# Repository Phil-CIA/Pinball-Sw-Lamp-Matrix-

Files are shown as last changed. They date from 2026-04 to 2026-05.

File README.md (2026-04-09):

# Pinball Switch + Lamp Matrix Board

8x4 lamp matrix driver and 8x4 switch matrix scanner board for a pinball machine.

## Architecture (current)
- **Lamp rows (8):** high-side smart switches (2× `VNQ7E100AJTR`, 4ch each)
- **Lamp columns (4):** low-side MOSFET sinks
- **Switch columns (4):** `LMV393` comparators (5V powered, OD outputs pulled up to 3.3V)
- **Output expansion:** 2× `74HC595` @ 3.3V for deterministic row/column bit patterns

## Repo layout
- `hardware/` – KiCad project files and production exports
- `firmware/` – PlatformIO / ESP-IDF bring-up firmware
- `docs/` – design notes, project status, review notes, and bring-up plans
- `BOM/` – key part numbers and alternates

## Project references
- `docs/PROJECT_STATUS.md` – current state, locked assumptions, and active priorities
- `docs/NEXT_ITERATION.md` – parking lot for ideas, risks, and restart notes
- `docs/SCHEMATIC_REVIEW.md` – design review and cleanup notes captured during the pre-order review
- `docs/BRINGUP_CHECKLIST.md` – first-board arrival, assembly, and power-up checklist
- `docs/PINMAP.md` – signal naming, connector grouping, and board-mating draft map
- `docs/PCB_REVIEW_CHECKLIST.md` – pre-order hardware checklist
- `docs/GITHUB_REPO_SETUP.md` – suggested GitHub repo metadata and settings
- `BOM/key_parts.md` – important component choices
- `CONTRIBUTING.md` – repo workflow and update expectations
- `SECURITY.md` – reporting guidance for risky or security-related issues
- `CHANGELOG.md` – notable repo changes over time

## Status
Rev 1 hardware was ordered on **2026-04-09**.

- **Hardware:** schematic, PCB snapshots, Gerbers, drill files, BOM, and production ZIP are checked in under `hardware/`
- **Order state:** PCB + stencil ordered, with parts ordered separately
- **Current phase:** wait for hardware and prepare bench bring-up
- **Firmware:** verified ESP32-C6 ESP-IDF bring-up scaffold is present under `firmware/`

## Next Steps
- keep the ordered Rev 1 package and notes as the reference point
- assemble and inspect the first boards when they arrive
- short-check `18V`, `5V`, and `3.3V` before full power-up
- validate ESP32, shift-register outputs, and switch-column reads on bench hardware
- run one-row / one-column lamp tests, then a full matrix scan
- capture any Rev 2 findings after first hardware validation

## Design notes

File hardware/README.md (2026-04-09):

# Hardware Notes

This folder contains the KiCad project files and production exports for the pinball switch + lamp matrix board.

## Current state
- `Pinball Matrix board Rev 1.kicad_sch` is the checked-in schematic source for Rev 1.
- `hardware/` also contains routed PCB snapshots, Gerbers, drill files, a BOM CSV, and the zipped production package used for ordering.
- Rev 1 PCB + stencil were ordered on `2026-04-09`; treat the ordered files as the frozen reference until hardware bring-up starts.

## Recommended use
1. Use `../docs/SCHEMATIC_REVIEW.md` for design review context and accepted tradeoffs.
2. Use `../docs/BRINGUP_CHECKLIST.md` when the first boards arrive.
3. Record any assembly or bench findings back into `../docs/NEXT_ITERATION.md` and `../docs/PROJECT_STATUS.md`.

## Caution
- More than one PCB snapshot exists in this folder (`pre route`, `routed`, `routed power`).
- If a post-order edit is made, clearly note whether it belongs to the frozen Rev 1 archive or to future Rev 2 work.

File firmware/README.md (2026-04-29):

# Firmware

Preferred workflow: **PlatformIO** using the verified **ESP-IDF** environment for ESP32-C6.

## Layout
- `src/` - production firmware entry point (PlatformIO default)
- `bringup/` - one-off test programs and notes

## Build (PlatformIO)
From `firmware/`:
- `python -m platformio run`
- `python -m platformio run -t upload --upload-port COM4`
- `python -m platformio device monitor --port COM4 --baud 115200`

If ESP-IDF tool version checks block a local bring-up build, run in the same shell session:
- PowerShell: `$env:IDF_MAINTAINER='1'`

## Notes
- Verified on 2026-04-06: `esp32-c6-devkitm-1` currently builds with `framework = espidf` in PlatformIO.
- If you later move to a board definition with Arduino support, an Arduino environment can be added back into `platformio.ini`.
- Update the `board = ...` value in `platformio.ini` if your exact ESP32-C6 dev kit differs.
- For this repository, build from the no-space path (`C:\cfhe\Pinball-Sw-Lamp-Matrix\firmware`) when possible. Path whitespace has caused intermittent ESP-IDF failures.

## Bring-up Runtime Modes (2026-04-29)
Current firmware provides fixed bring-up runtime behavior selected in `src/main.cpp` using `kRuntimeMode`.

Available modes:
- `RuntimeMode::LampAttract`
	- Low-duty attract chase for lamp mapping and brightness sanity
	- Timing controlled by `ATTRACT_SLOT_MS` and `ATTRACT_ON_MS`
- `RuntimeMode::SwitchScan`
	- Rows are scanned continuously with lamp columns held off
	- Switch-column reads are sampled per row and accumulated
	- Serial prints include:
		- `HB ...`
		- `SWITCH_SCAN row=... hits[rX]=...`
		- `SW_EDGE/s: ...`
		- `CTRL_I2C edges/s: ...`
- `RuntimeMode::I2cSlaveRegmap` (current default)
	- Matrix board exposes I2C slave register map at `0x24` on `GPIO2/GPIO3`
	- Registers and commands align to control-board contract (`0x00..0x07`, `0x40..0x43`, `0xF0..0xF3`, `0x20/0x80/0xE0`)
	- OLED remains active in this mode using software I2C on `GPIO7/GPIO6`
	- OLED view includes banner status, live 8x5 lamp grid, and link telemetry pane
	- Link state detection includes `WAIT`, `LIVE`, and `DEGRADED` (TX stall)

## Current validated pin map
- Shift register drive:
	- `S_Data = GPIO15`
	- `S_CLK = GPIO22`
	- `S_latch = GPIO23`
	- `SR_/OE = GPIO10` (driven low to enable outputs)
- Switch comparator outputs:
	- `SW_COL_0 = GPIO18`
	- `SW_COL_1 = GPIO19`
	- `SW_COL_2 = GPIO20`
	- `SW_COL_3 = GPIO21`
- OLED:
	- `SDA = GPIO7`
	- `SCL = GPIO6`

## Quick verify sequence
1. Build and upload from `C:\cfhe\Pinball-Sw-Lamp-Matrix\firmware`
2. Open serial monitor on COM4
3. Confirm startup shows `Runtime mode: I2C_SLAVE_REGMAP ...`
4. Confirm `ssd1306_sw_init(GPIO7/6 @0x3C) -> 0 (ESP_OK)`
5. Confirm per-second updates show `HB`, `I2C_SLAVE ...`, and `LINK state=...`

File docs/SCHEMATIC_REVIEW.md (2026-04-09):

# Schematic Review and Cleanup Notes

Review dates: **2026-04-06** and follow-up **2026-04-07**

This note captures the current schematic cleanup work that should be finished **before spending time routing the PCB**.

Scope reviewed:
- `hardware/Pinball Matrix board Rev 1.kicad_sch`
- repo documentation and footprint/library setup

> This is a schematic/design review note based on the checked-in KiCad source and repo contents. It should be used as the cleanup guide before layout work continues.

---

## Follow-up review status (2026-04-07)
- Fresh repo check showed `git status -sb` clean.
- The currently saved KiCad files in `hardware/` show `LastWriteTime` around **2026-04-06 7:28 AM**, so the repo copy available for review is **not within the last hour**.
- An updated netlist is **not required** for this text/design review, but a saved netlist/ERC export would help with deeper connectivity cross-checking later.
- Because no newer KiCad save was visible in the repo copy, the block-by-block notes below apply to the **current saved schematic version**.

---

## Current pre-order repo status (2026-04-09)
- Latest repo state includes **production-oriented outputs** under `hardware/`, including:
  - routed PCB snapshots
  - BOM CSV
  - gerbers / drill files
  - zipped production package
- Current source review shows several earlier concerns are now effectively addressed:
  - `U3` now uses a dedicated `ESP32-C6-DevKit-Amazon` footprint entry
  - test points are assigned to `KEYSTONE_5015`
  - output connectors use `.156" / 3.96 mm` KK-396 style footprints
  - power input plan uses JST XH connectors with shared `18V` and `GND` pins, and a separate lighter-current `5V` pair
  - planned routing approach uses `0.3 mm` minimum signal traces and `2.0–2.5 mm` row-current traces with VNQ thermal-pad stitching
- Based on the schematic/block review to date, **no show-stopper has been identified** for moving forward with Rev 1.
- Remaining caution items before ordering are mostly execution checks:
  - run KiCad ERC/DRC on the exact final file you intend to order
  - confirm the authoritative PCB/gerber set among the saved routed snapshots
  - sanity-check connector pin order and polarity one last time against the harness

## High-priority items before PCB routing

| Priority | Item | Review note / action |
|---|---|---|
| High | `JD1` connector mismatch | `JD1` uses a `Conn_01x24_MountingPin` symbol while the assigned footprint is `Connector_Molex:Molex_KK-396_5273-12A_1x12_P3.96mm_Vertical`. The symbol pin count and footprint pin count must be made consistent. |
| High | `U2` controller footprint mismatch | `U2` is labeled `ESP32-C6-DevKitM-Amazon`, but the assigned footprint is `RF_Module:ESP32-C3-DevKitM-1`. Confirm the actual controller board/module and correct the footprint now. |
| High | `U5` / `U6` comparator package choice | `LMV393` is present, but the final footprint/package choice still needs to be locked down and verified against the intended assembly plan. |
| High | Test-point footprints | `TP6`–`TP15` should be assigned the chosen small SMT test-point footprint (`Keystone 5015` was selected). |
| High | `F1` / `F2` polyfuse footprints | Polyfuse footprints still need to be replaced with a real KiCad footprint instead of placeholder-style text. |
| High | Ground strategy | `GND` and `GNDD` are both used in the schematic. Decide whether they remain split or are tied intentionally with a documented single-point/net-tie strategy. |

## Medium-priority cleanup items

- **Normalize signal naming** to match `docs/PINMAP.md`
  - `S_CLK` → `SR_SCLK`
  - `S_latch` → `SR_LATCH`
  - `S_Data` → `SR_DATA0`
  - `S_Data_1` → `SR_DATA1`
  - `Sw_Col_0...3` → `SW_COL_0...3`
- **Remove duplicated naming styles** such as:
  - `+3.3V` vs `+3V3`
  - `I2C SCL` vs `I²C SCL`
  - `Row 3` vs `Row_3`
- **Confirm connector family callouts**
  - some connector values use `B4B-XH-A` while footprints point to JST EH footprints; verify the actual intended family/pitch
- **Rename MOSFET references consistently**
  - devices using value `IRLR024` should use transistor-style references (`Qx`) instead of inductor-style references if they are MOSFETs
- **Review optional EMI tuning parts**
  - ferrites/snubber parts should be marked and documented as default-fit vs DNP for rev A
- **Re-check bulk capacitor assumptions**
  - verify voltage rating, technology, and effective capacitance on the 18V lamp rail

## Block-by-block design review

### 1) Power entry and protection
- Good signs: PTC fuses, TVS parts, and bulk/decoupling capacitors are present in the schematic.
- Follow-up review on 2026-04-08: moving to physically larger **per-rail TVS parts** is acceptable and can improve layout/rework, as long as the standoff/clamp ratings still match each rail.
- Before routing, confirm real footprints for `F1` / `F2`, verify the bulk-cap voltage margin on the lamp rail, and keep the TVS return path physically short and wide.
- Keep the fuse upstream of the TVS in the final PCB layout.

### 2) Lamp row driver block (`VNQ7E100AJTR`)
- The 8-row high-side architecture still fits the intended lamp-matrix design.
- Confirm EPAD grounding, strap-pin defaults, and any unused-channel handling before layout.
- Keep the row outputs and connector naming aligned with `docs/PINMAP.md`.

### 3) Lamp column sink block
- The low-side sink approach still looks appropriate for the matrix concept.
- Main cleanup item: confirm package/current capability and use consistent transistor-style references for MOSFET parts.
- Verify any gate resistors, pulldowns, and EMI/ringing mitigation parts you want stuffed by default.

### 4) Switch input comparator block (`LMV393` + clamps)
- The comparator-based switch readback approach is still reasonable for the design.
- Follow-up review on 2026-04-08 against the updated source confirms `LMV393` comparators with `BAT54C,215` clamp diodes and the expected `Ref_Comp1` / `Ref_Comp2` reference network.
- I do **not** see a stop-the-design issue here; the block concept looks fine for now.
- Keep the comparator outputs clearly referenced to the 3.3V logic side, and only add hysteresis later if bench testing shows chatter or noise around the threshold.
- No exposed-pad package is needed here; a standard SOIC-8 / TSSOP-8 style comparator package remains the practical choice.

### 5) Shift-register / logic-output block (`74HC595`)
- This block still matches the firmware bring-up concept.
- `/OE` and `/MR` should have explicit boot-safe defaults so the lamps do not glitch during startup.
- Normalize the control-net labels to `SR_SCLK`, `SR_LATCH`, `SR_DATA0`, and `SR_DATA1`.

### 6) Controller / dev-board block (`U2`)
- This remains a top cleanup item because the symbol name and assigned footprint do not yet agree.
- Confirm whether the design is targeting a temporary dev board, a module footprint, or a board-to-board control header.
- If GPIO assignments change, keep `docs/PINMAP.md` and firmware notes synchronized.

### 7) Connectors, test points, and board mating
- Connector families and exact pin counts still need to be frozen before routing.
- `JD1` must be corrected before layout because the symbol and footprint currently disagree.
- Assign the chosen `Keystone 5015` footprint to the debug test points and keep the board-mating notes in `docs/PINMAP.md` up to date.

## Repo / footprint-library cleanup

The schematic currently references external or non-portable footprint/library names such as:
- `PCM_JLCPCB:*`
- `Captain fantastic footprints:*`
- `POWERSSO-16_STM`

### Repo risk
At review time, the repo does **not** contain tracked KiCad footprint libraries (`*.kicad_mod`) or symbol libraries (`*.kicad_sym`). That means footprint resolution depends on the local KiCad environment.

### Recommended fix
Choose one of these approaches before layout gets deeper:
1. **Commit required custom footprints/libraries into the repo** under a dedicated hardware library folder, or
2. **Document the required external libraries clearly** in `hardware/README.md` so the project opens predictably on another machine.

## Suggested cleanup order
1. Lock the exact controller/dev-board footprint for `U2`
2. Fix `JD1` symbol-to-footprint pin-count mismatch
3. Assign/confirm comparator, fuse, and test-point footprints
4. Normalize signal names to match `docs/PINMAP.md`
5. Decide and document `GND` vs `GNDD`
6. Re-run a formal KiCad ERC/footprint check in KiCad before routing continues

## Notes to carry into PCB layout
- Keep the logic/debug connector and lamp-power connector concerns clearly separated
- Keep test points on logic/control nets easy to probe
- Do not assume all custom footprints will resolve on a fresh machine unless the repo includes them or the setup is documented

## Pre-routing go / no-go checklist

Before committing to the heavy PCB routing, confirm these items:

- [ ] **Row current estimate is written down**
  - worst-case active row current for the `555` lamp matrix is understood and accepted
- [ ] **Connector current handling is acceptable**
  - input and output connectors are confirmed for real machine wiring/current pulses
- [ ] **Trace widths are chosen in mm**
  - lamp supply and high-current row/column paths are planned around the agreed wider copper approach
- [ ] **VNQ thermal plan is intentional**
  - copper area, pad treatment, and short current paths are accounted for
- [ ] **Power-entry return paths are short and wide**
  - fuse, TVS, bulk caps, and ground return placement are kept tight
- [ ] **Comparator reference area is kept quiet**
  - threshold/reference nodes are not sharing thin noisy returns with lamp current
- [ ] **Connector pin order is frozen before routing**
  - avoid rework after the large current paths are already placed
- [ ] **Any DNP/tuning parts are clearly marked**
  - especially EMI/filtering options on lamp outputs

If these are mostly true, the board is in a reasonable state to continue routing.

## Review log
- 2026-04-06: initial schematic cleanup review captured in repo documentation.
- 2026-04-07: follow-up review confirmed the repo copy had no newly saved KiCad files and added a block-by-block design review section.
- 2026-04-08: pulled the latest remote KiCad updates; confirmed the switch-input comparator block and larger rail-TVS direction are conceptually acceptable.

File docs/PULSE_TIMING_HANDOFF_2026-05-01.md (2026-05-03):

# Pulse Timing Handoff - 2026-05-01

Status: Local implementation drafted on this workstation, not yet built or bench-validated.
Scope: Matrix shift-register timing, lamp-first row sequencing, and follow-on switch sampling placement.

## Why this handoff exists
The important point from today's review is that determinism has to come from the shift-register write itself.
The time-critical primitive should do only this:

1. Take the current row/column image.
2. Apply the intended row/column value.
3. Clock and latch the frame.

No scan logic, no conditional behavior, and no readback work should live inside that primitive.
That keeps row-to-row edge placement repeatable and makes the logic analyzer captures interpretable.

## Current status on this workstation
Primary source file: firmware/src/main.cpp

Local edits have already been made in that file to move the non-attract scan path to an explicit scheduler with microsecond deadlines.
The scheduler now uses these phases:

1. Blank
2. Drive
3. Settle
4. Sample
5. Hold

The current local implementation also separates row and column SR writes instead of relying on one combined row transition.

Important limitation: this workstation shell does not have ESP-IDF initialized, so the change has not been built here. `idf.py` was not available on `PATH`, and editor diagnostics only reported missing ESP-IDF include paths.

## Lamp-first design decision
The same base SR routine applies to both lamp drive and switch scanning, but the next bench target should be lamp timing first.
Reason: if row and column transitions are electrically clean for lamps, the same scheduler structure gives a stable foundation for switch sampling afterward.

The intended per-row write order is:

1. Blank write: all rows off, all columns off.
2. Row-on write: target row active, columns still off.
3. Column-on write: same row active, desired columns driven.
4. Settle delay: allow external hardware to reach a stable state.
5. Sample point: used for switches later, at a fixed delay from the final latch.
6. Columns-off write: same row still selected, columns forced off.
7. Dead-time: short off interval to cover driver/storage/RC recovery.
8. Row-off write: force row inactive before the next row begins.

This ordering avoids both of the bad overlap cases:

- new row with old columns
- old row with new columns

## Timing model to bench-tune
Current local constants in firmware/src/main.cpp:

- `SWITCH_SCAN_ROW_MS = 5`
- `ROW_BLANK_US = 100`
- `ROW_SETTLE_US = 100`
- `ROW_OFF_DEADTIME_US = 50`

These are starting values only. The MCU is not the limiting factor; the external devices are. Budget must cover:

- shift-register propagation and latch behavior
- row-driver turn-on and turn-off timing
- column-line RC settling
- any analog or GPIO recovery before a sample is trusted

## What was changed locally
In firmware/src/main.cpp, the local uncommitted edit does the following:

1. Adds a dedicated `RowPhase` enum and `RowScheduler` state.
2. Adds `sr_write_image(rowByte, colByte)` so the SR write path stays simple and constant-time.
3. Replaces the old coarse row-step logic with explicit microsecond phase deadlines.
4. Splits non-attract row service into separate writes for row-only and row-plus-columns.
5. Moves switch sampling to the fixed post-settle sample phase.
6. Adds heartbeat visibility for scheduler phase and overrun count.

This is the right direction, but it still needs a real build and bench capture before commit.

## Outstanding files to carry and commit
As of this handoff, the matrix repo has these outstanding modified files:

- `firmware/src/main.cpp`
- `docs/PULSE_TIMING_HANDOFF_2026-05-01.md`

Control-board repo on this workstation showed no outstanding changes.

## Required validation on the other workstation
Use an ESP-IDF-enabled shell on the other workstation.

1. Pull the latest matrix repo state from the remote.
2. Bring over or reapply the local edits if they are not yet committed.
3. Run `idf.py build` in the firmware directory.
4. Capture LA traces on at least: row output, SR latch, SR clock, and one column input.
5. Confirm this sequence electrically:
   - blank frame
   - row-on / columns-off frame
   - row-on / columns-on frame
   - settle interval
   - sample instant
   - columns-off frame
   - row-off frame
6. Tune `ROW_BLANK_US`, `ROW_SETTLE_US`, and `ROW_OFF_DEADTIME_US` until overlap is gone and timing is repeatable.

## Commit target after validation
If the build passes and the waveform looks correct, commit the two modified matrix files above as the timing-stabilization checkpoint.

Suggested commit scope:

- deterministic SR scheduler and explicit row/column timing sequence
- updated handoff notes with lamp-first validation plan

## Non-goals for this pass
Do not widen this pass into gameplay or control integration yet.
Still out of scope until the lamp timing is proven:

- control-board solenoid coupling
- scoring behavior
- audio parity work
- broader protocol feature work beyond what is needed to exercise lamp timing

## Immediate next action on the other workstation
Open an ESP-IDF shell, build the matrix firmware, bench the lamp waveform first, then commit the outstanding matrix files once the timing constants are validated.

Last updated: 2026-05-03
Owner for next step: bench firmware dev workstation

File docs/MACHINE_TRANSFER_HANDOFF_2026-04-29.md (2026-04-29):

# Machine Transfer Handoff - 2026-04-29

## Snapshot
- Repo: `Pinball-Sw-Lamp-Matrix`
- Branch: `main` (local working tree has uncommitted housekeeping updates)
- Active firmware mode: `RuntimeMode::I2cSlaveRegmap` in `firmware/src/main.cpp`
- Control-link role: matrix board as I2C slave at `0x24` on `GPIO2/GPIO3`
- OLED role: active in slave mode using software I2C on `GPIO7/GPIO6`

## What Was Completed Today
1. Implemented and stabilized matrix I2C slave register map flow.
2. Added diagnostics and cleaned telemetry counters (`badWrites` vs `ignoredWrites`).
3. Re-enabled OLED output while slave mode is active using software I2C.
4. Added OLED display contract v1:
   - top banner status elements
   - 8x5 matrix grid from lamp row buffer
   - right telemetry pane (sweep / trace)
   - link states (`WAIT`, `LIVE`, `DEGRADED`) with TX-stall detection
5. Housekeeping updates made in:
   - `firmware/src/main.cpp`
   - `firmware/README.md`
   - `CHANGELOG.md`

## Current Constraints
- BAT54 switch-path hardware update is pending (user has BAT54S incoming).
- Switch validation is intentionally deferred until BAT54S replacement is complete.
- PlatformIO build still reports flash warning:
  - expected 4MB, detected 2MB
  - currently non-blocking for bring-up workflow

## Verified Runtime Evidence
- Build succeeds from no-space path: `C:\cfhe\Pinball-Sw-Lamp-Matrix\firmware`
- Upload succeeds on COM4.
- Boot log confirms:
  - `Runtime mode: I2C_SLAVE_REGMAP addr=0x24 SDA=GPIO2 SCL=GPIO3`
  - `ssd1306_sw_init(GPIO7/6 @0x3C) -> 0 (ESP_OK)`
- Link telemetry shows active `rx/tx` progression and link state output.

## Next Mainline Steps
1. Keep default mode in `I2cSlaveRegmap` until switch hardware is updated.
2. After BAT54S install:
   - validate physical switch closures against registers `0x40..0x43`
   - confirm no false edges/noise
3. Run control-link acceptance checks:
   - stable `LIVE` state
   - no sustained `DEGRADED`
   - lamp row writes reflected correctly in grid/buffer

## Resume Commands
From PowerShell:

```powershell
Set-Location C:\cfhe\Pinball-Sw-Lamp-Matrix\firmware
C:\Users\user\.platformio\penv\Scripts\platformio.exe run
C:\Users\user\.platformio\penv\Scripts\platformio.exe run --target upload
C:\Users\user\.platformio\penv\Scripts\platformio.exe device monitor --port COM4 --baud 115200
```

## Git Checklist Before Push
If you want to capture this checkpoint as a commit:

```powershell
Set-Location C:\cfhe\Pinball-Sw-Lamp-Matrix
git status --short
git add firmware/src/main.cpp firmware/README.md CHANGELOG.md docs/MACHINE_TRANSFER_HANDOFF_2026-04-29.md
git commit -m "Matrix slave+OLED integration: display v1, link states, and housekeeping"
git push
```

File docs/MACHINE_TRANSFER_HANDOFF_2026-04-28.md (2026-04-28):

# Machine Transfer Handoff (2026-04-28)

Purpose: resume matrix-board bring-up tomorrow from another machine, then continue execution here with minimal context loss.

## Repo and Branch
- Repo: `Phil-CIA/Pinball-Sw-Lamp-Matrix-`
- Branch: `main`
- Working tree status at handoff creation: clean

## Last Pushed Commits (newest first)
- `0d4cc17` Ignore local bring-up capture logs
- `850f767` Checkpoint: Rev1 hardware edits and firmware platform config
- `8a48dfa` Add switch-scan bring-up mode and update checkpoint docs

## Current Firmware State (Matrix Repo)
- File: `firmware/src/main.cpp`
- Runtime mode selector exists:
  - `RuntimeMode::LampAttract`
  - `RuntimeMode::SwitchScan`
- Current default is:
  - `kRuntimeMode = RuntimeMode::SwitchScan`
- Validated pins:
  - Shift register: `DATA=GPIO15`, `CLK=GPIO22`, `LATCH=GPIO23`, `OE_N=GPIO10`
  - Switch columns: `SW_COL_0..3 = GPIO18..GPIO21`
  - OLED: `SDA=GPIO7`, `SCL=GPIO6`
  - Control-link monitor: `SDA=GPIO2`, `SCL=GPIO3`

## Bench Findings So Far
- Lamp hardware path now mostly functional after correcting swapped gate resistor placements on 3 of 4 lamp columns.
- Brightness concern addressed in firmware by low-duty attract pulse timing.
- Switch validation mode implemented and running with telemetry:
  - `HB ...`
  - `SWITCH_SCAN row=... hits[rX]=...`
  - `SW_EDGE/s: ...`
  - `CTRL_I2C edges/s: ...`
- OLED is considered "good enough" for bring-up status display.

## Hardware Action Item (Comparator Clamp)
- Current fitted clamp device: BAT54C in SOT-23.
- For signal-to-rails clamp use at comparator input, BAT54S topology is preferred.
- Temporary field fix discussed:
  - Lift BAT54C pin tied to +5 side (pin 1 in your described orientation).
  - Keep signal node and GND clamp side connected.
  - Add external `1N4148` with **anode at signal**, **cathode at +5V**.

## Build/Upload Notes (important)
- Preferred build path: no-space path to avoid ESP-IDF/PlatformIO path issues:
  - `C:\cfhe\Pinball-Sw-Lamp-Matrix\firmware`
- In PowerShell, if tool version guard blocks build:
  - `$env:IDF_MAINTAINER='1'`
- Typical commands:
  - `C:\Users\user\.platformio\penv\Scripts\platformio.exe run -e esp32c6_espidf`
  - `C:\Users\user\.platformio\penv\Scripts\platformio.exe run -e esp32c6_espidf -t upload --upload-port COM4`
  - `C:\Users\user\.platformio\penv\Scripts\platformio.exe device monitor --port COM4 --baud 115200`

## Tomorrow Morning Plan (execution order)
1. Hardware pre-check
- Confirm temporary clamp fix applied (or BAT54S replacement if parts arrived).
- Verify no accidental shorts around comparator input network and +5/GND rails.

2. Firmware sanity
- Pull latest `main`.
- Build and upload from `C:\cfhe\Pinball-Sw-Lamp-Matrix\firmware`.
- Confirm boot banner and runtime mode line in serial output.

3. Switch verification pass
- Keep runtime mode in `SwitchScan`.
- Manually actuate known switches and confirm:
  - `SW_EDGE/s` increments on expected columns.
  - `SWITCH_SCAN hits[rX]` increments on expected row/col combinations.
- Record mismatches in a row/col table.

4. Lamp verification pass
- Temporarily switch to `LampAttract` if needed for mapping/brightness checks.
- Confirm expected lamp mapping and acceptable brightness/thermal behavior.

5. End-of-session hygiene
- Save logs/notes, update `docs/BRINGUP_CHECKLIST.md` and `CHANGELOG.md` if new findings occur.
- Commit only intentional source/docs changes.

## Suggested Resume Prompt (for tomorrow)
"Resume matrix board bring-up from docs/MACHINE_TRANSFER_HANDOFF_2026-04-28.md. Start in RuntimeMode::SwitchScan, verify switch row/column hits and edge counters, then optionally run RuntimeMode::LampAttract for lamp mapping/brightness check. Build/upload from C:\\cfhe\\Pinball-Sw-Lamp-Matrix\\firmware and log pass/fail with measured observations."

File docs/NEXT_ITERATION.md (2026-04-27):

# Next Iteration / Parking Lot

This file is the project **parking lot** for ideas, questions, risks, and assumptions that should be captured now and revisited later.

Use it to avoid losing useful thoughts while keeping the current work focused.

## How to use this file
- add short notes, not long essays
- keep the newest items near the top of each section
- mark items as resolved when they are closed
- move stable decisions into `README.md`, `docs/PROJECT_STATUS.md`, or the schematic notes

---

## Current next-iteration focus
- ✅ 5V and 3.3V rails confirmed up on assembled Rev 1 board (2026-04-27)
- Active phase: firmware flash → logic validation → staged lamp testing
- keep `docs/PINMAP.md` and bring-up notes ready for first-board debugging

## Restart here when hardware arrives
1. **Visual inspection**
   - polarity/orientation check for diodes, TVS parts, connectors, and the ESP32 board
   - inspect VNQ thermal pad soldering and stencil results
   - check for bridges, tombstones, and damaged pads

2. **Pre-power checks**
   - continuity / resistance check on `18V`, `5V`, `3.3V`, and `GND`
   - verify fuse and TVS placement against the schematic
   - confirm connector polarity and harness pin 1 direction

3. **First power-up**
   - bring the board up with current limiting if possible
   - verify `5V` and `3.3V` rails first
   - then confirm the ESP32-C6 boots and the firmware still runs as expected

4. **Functional validation**
   - verify shift-register activity
   - verify all four switch-column comparator outputs
   - test one lamp row / one lamp column first
   - then move to a full matrix scan

5. **Capture findings**
   - record any thermal, noise, connector, or routing surprises
   - note anything that should roll into a likely Rev 2

## Parking lot
- confirm whether the final firmware should stay ESP-IDF-only or also support Arduino later
- decide if any lamp column protection or snubber options should be stuffed by default after bench testing
- keep `docs/PINMAP.md` updated as the source of truth for signal naming and board-mating notes

## Assumptions to validate on real hardware
- `VNQ7E100AJTR` remains the preferred high-side row driver
- `LMV393` input conditioning is the right switch-scan approach without extra hysteresis
- `74HC595` output expansion is sufficient for the first revision
- the current power-entry protection plan matches the real machine environment
- `1 oz` copper with `0.3 mm` minimum signal traces and `2.0–2.5 mm` row-current traces is adequate for Rev 1

## Things that may need reconsideration after bring-up
- connector family / harness approach in long-term service
- row / column labeling convention on the installed machine
- default boot-safe behavior for lamp outputs
- EMI tuning parts to stuff by default vs DNP
- firmware architecture once hardware validation is complete

## Open questions
- what real lamp current and connector heating are seen on the bench?
- do any comparator thresholds or reference values need tweaking after real switch tests?
- which DNP protection / tuning parts should become default-fit for Rev 2?
- should the repo track a formal decision log later?

## Notes log
- 2026-04-27: **5V and 3.3V rails confirmed up on assembled Rev 1 board.** Active bring-up phase started.
- 2026-04-27: **Rev 2 note:** 0805 component pads benefit from ~1.5 mm trace width at the pad; update design rules for Rev 2.
- 2026-04-09: Rev 1 PCB, stencil, and parts were ordered. Expected flow is to pause active design work, wait for the hardware, and resume with a structured bring-up pass when the boards arrive.
- 2026-04-07: follow-up schematic review used the current saved repo copy; if new KiCad edits are made, save/export before the next review pass.
- 2026-04-06: initial parking-lot document added for repo housekeeping and iteration tracking.

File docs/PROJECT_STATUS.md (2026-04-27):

# Project Status

## Summary
This project is building a combined **8x4 lamp matrix driver** and **8x4 switch matrix scanner** board for a home-edition pinball machine.

## Current state (2026-04-27)
### Hardware
- Rev 1 schematic, PCB snapshots, Gerbers, drill files, BOM, and production ZIP are checked in under `hardware/`
- PCB, stencil, and parts were ordered on **2026-04-09**
- Board was assembled and **5V and 3.3V rails confirmed up** on **2026-04-27**
- Current phase: **active bring-up** — logic validation and staged lamp testing
- Because several PCB snapshots exist, the ordered Rev 1 package should be treated as the frozen reference point for this bring-up session

### Rev 1 assumptions locked during review
- `T10/555` incandescent lamps at `6.3V`
- roughly `28` lamps in the matrix scan envelope
- `1 oz` copper
- `0.3 mm` minimum signal traces
- `2.0–2.5 mm` row/high-current traces
- solid `GND` pour strategy preferred
- lamp outputs via `.156" / 3.96 mm` KK-396 class connectors
- power entry via JST XH, with `18V` and `GND` shared across two pins each and `5V` on a lighter-current pair

### Firmware
- PlatformIO project is present under `firmware/`
- Verified environment: `esp32-c6-devkitm-1` using **ESP-IDF**
- Bring-up code currently shifts a walking test pattern and reads four switch-column inputs

### Documentation
- Design review notes live in `docs/SCHEMATIC_REVIEW.md`
- Parking / restart notes live in `docs/NEXT_ITERATION.md`
- First-board arrival plan now lives in `docs/BRINGUP_CHECKLIST.md`
- Pin and connector mapping remains in `docs/PINMAP.md`

## Immediate next priorities
1. Flash and confirm ESP32-C6 bring-up firmware boots without reset loop
2. Probe `SR_SCLK`, `SR_LATCH`, `SR_DATA0` and confirm shift-register activity
3. Read all four `SW_COL_0..SW_COL_3` inputs and compare with expected states
4. Test one lamp row + one lamp column before running a full matrix scan
5. Record rail values, current draw, thermal notes, and any mapping surprises

## Open questions for bring-up / Rev 2
- actual measured lamp current and connector heating on real hardware
- whether any snubber / EMI options need to be stuffed by default
- any connector pinout or labeling adjustments after first install
- whether firmware remains ESP-IDF-only or later adds Arduino support

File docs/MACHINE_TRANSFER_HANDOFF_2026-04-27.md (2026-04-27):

# Machine Transfer Handoff (2026-04-27)

Purpose: resume matrix-board bring-up on your development-station PC without losing current context.

## Repo and Branch
- Repo: `Phil-CIA/Pinball-Sw-Lamp-Matrix-`
- Branch: `main`
- This handoff was created in the matrix-board repo (correct target).

## Current Hardware/Design State
- You indicated this is the latest matrix-board PCB revision session.
- Local repo currently contains unsaved-in-chat but real working changes in KiCad files (left untouched by this handoff commit).
- Existing repo docs still describe the Rev 1 bring-up flow and are valid as the startup checklist baseline.

## Current Bench Stage
- Stage: **assembled, not powered yet**.
- Immediate objective: safe first power-up and logic validation before wider lamp stress testing.

## First Session Plan on Dev Station
1. Bench prep and stop conditions
   - Prepare current-limited bench supply, DMM, and scope/logic probe.
   - Set hard stop conditions before power: overcurrent, wrong rail, unusual heat/smell.

2. Unpowered checks
   - Visual check orientation/polarity/connectors and solder quality.
   - Continuity/short checks:
     - `18V` to `GND`
     - `5V` to `GND`
     - `3.3V` to `GND`
   - Verify no accidental coupling from lamp rail into logic rails.

3. First power-up (current-limited)
   - Power up conservatively.
   - Verify `5V` rail, then `3.3V` rail.
   - Check for abnormal heating in regulator/protection/driver areas.

4. Firmware/logic smoke test
   - Run current ESP32-C6 bring-up firmware baseline.
   - Confirm boot output and no reset loop.
   - Probe:
     - `SR_SCLK`, `SR_LATCH`, `SR_DATA0`
     - `SW_COL_0..SW_COL_3`

5. Boot safety behavior
   - Confirm `/OE` and `/MR` are safe at startup.
   - Confirm no unintended lamp flash on boot.

6. Staged lamp validation
   - Test one row + one column first.
   - Expand to full matrix scan only after first pass is stable.
   - Watch connector temperature, supply sag, and thermal hotspots.

7. Capture findings immediately
   - Record rail values, current draw, thermal notes, and mapping/polarity findings.
   - Update docs with dated notes before ending the session.

## Use These Files First
- `README.md`
- `docs/PROJECT_STATUS.md`
- `docs/BRINGUP_CHECKLIST.md`
- `docs/NEXT_ITERATION.md`
- `docs/PINMAP.md`
- `firmware/src/main.cpp`

## Suggested First Prompt on Dev Station
"Resuming matrix-board bring-up on assembled unpowered hardware. Use docs/BRINGUP_CHECKLIST.md and docs/NEXT_ITERATION.md as the runbook. Execute staged checks: unpowered continuity, current-limited first power, logic probe of SR_SCLK/SR_LATCH/SR_DATA0 and SW_COL_0..SW_COL_3, then one-row/one-column lamp test before full scan. Log measured values and pass/fail at each phase."

## Important Scope Note
- This commit only adds this handoff document.
- Existing KiCad modifications in `hardware/` were intentionally not included in this commit.

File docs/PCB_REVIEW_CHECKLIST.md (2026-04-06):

# PCB Review Checklist (before ordering)

## 1) VNQ7E100AJTR (PowerSSO-16) EPAD plan
- [ ] EPAD is connected to **GND** copper (per datasheet intent).
- [ ] Add **via stitching** under/around EPAD to spread heat to other layers.
- [ ] Consider paste stencil **windowing** (avoid too much paste so part doesn’t float).
- [ ] Keep high-current loops short/wide (VCC -> VNQ -> harness -> return).

## 2) Decoupling placement
### VNQ7E100AJTR
- [ ] 100 nF ceramic placed as close as possible to VCC/GND pins (same side if possible).
- [ ] 1 uF ceramic placed close to the IC as well.
- [ ] Bulk cap near power entry and reasonably near the VNQs.

### LMV393 + 74HC595
- [ ] 100 nF at each IC, close to VCC/GND pins.

## 3) Power entry protection
- [ ] Fuse/PTC is upstream of TVS (TVS should not have to eat sustained faults).
- [ ] TVS return path to ground is **short + wide** (min loop inductance).
- [ ] Bulk electrolytic voltage rating margin OK for 18–22V rail + spikes.

## 4) Grounding / noise control
- [ ] Even if using one GND net, keep **snubber currents** and **lamp return currents**
      from sharing thin traces with comparator reference/divider returns.
- [ ] Keep comparator reference divider node physically quiet (short traces, local return).

## 5) Lamp row EMI tuning options (stuff/DNP)
Per row output at connector:
- [ ] Ferrite bead footprint in series with row line.
- [ ] RC snubber footprint: R (series) + C to GND (DNP by default).
- [ ] Keep these parts close to the connector to damp harness ringing.

## 6) 74HC595 boot safety
- [ ] /MR has a defined pull-up so the register doesn’t randomly clear.
- [ ] /OE default policy decided:
  - safer: /OE pulled HIGH (disabled) and firmware enables after shifting all-off pattern
- [ ] Confirm power-up behavior cannot flash lamps unintentionally.

## 7) Test points
- [ ] Add test points for: 3.3V, 5V, 18/22V, GND, S_CLK, S_LATCH, S_DATA, S_DATA_1
- [ ] Add test points for each switch column output (post-comparator) if possible.
- [ ] For small debug access, use a compact SMT loop test point footprint on key low-current signals.
- [ ] Keep high-current lamp nets on appropriately sized pads / connector access, not tiny logic-only test points.

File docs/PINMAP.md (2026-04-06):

# Pin and Connector Map

This file is the working source of truth for **signal naming**, **connector grouping**, and any future **board-to-board / HAT-style mating interface**.

> Status: draft for iteration planning. The final connector numbers and exact pin order are still **TBD**.

## Signal naming conventions

### Lamp matrix
- `LAMP_ROW_0` ... `LAMP_ROW_7` — high-side lamp row outputs
- `LAMP_COL_0` ... `LAMP_COL_3` — low-side lamp column sinks

### Switch scan
- `SW_COL_0` ... `SW_COL_3` — comparator outputs to the controller
- `SW_ROW_SCAN_0` ... `SW_ROW_SCAN_7` — row drive / scan naming placeholder if used in firmware or schematic notes

### Shift-register control
- `SR_SCLK` — shift clock
- `SR_LATCH` — storage/latch clock
- `SR_DATA0` — primary serial data line
- `SR_DATA1` — optional second serial data line if kept in the design
- `SR_OE_N` — optional active-low output enable for boot-safe control

### Power rails
- `VIN_LAMP` — lamp supply input (design target currently discussed around the machine lamp rail)
- `+5V_SW` — comparator/switch interface supply
- `+3V3_LOGIC` — logic/MCU domain
- `GND` — shared ground reference

---

## Current firmware bring-up GPIO map

These values match the present ESP-IDF bring-up code in `firmware/src/main.cpp`.

| Logical signal | ESP32-C6 GPIO | Direction | Notes |
|---|---:|---|---|
| `SR_SCLK` | `GPIO23` | Output | 74HC595 shift clock |
| `SR_LATCH` | `GPIO24` | Output | 74HC595 latch |
| `SR_DATA0` | `GPIO25` | Output | Main serial data |
| `SR_DATA1` | `GPIO26` | Output | Optional second data line |
| `SW_COL_0` | `GPIO19` | Input | Post-comparator switch column |
| `SW_COL_1` | `GPIO20` | Input | Post-comparator switch column |
| `SW_COL_2` | `GPIO21` | Input | Post-comparator switch column |
| `SW_COL_3` | `GPIO22` | Input | Post-comparator switch column |

## Draft connector grouping

### `J_PWR` — power entry
Working intent:
- `VIN_LAMP`
- `GND`
- optional local power distribution as needed for `+5V_SW` / `+3V3_LOGIC`

### `J_LAMP` — lamp matrix harness
Working signal set:
- `LAMP_ROW_0` ... `LAMP_ROW_7`
- `LAMP_COL_0` ... `LAMP_COL_3`
- return / ground pins as needed by harness strategy

### `J_CTRL` — controller or mating-board interface
Working signal set:
- `SR_SCLK`
- `SR_LATCH`
- `SR_DATA0`
- `SR_DATA1` (optional)
- `SR_OE_N` (recommended spare / future-safe control)
- `SW_COL_0` ... `SW_COL_3`
- `+3V3_LOGIC`
- `GND`

---

## Board-mating / HAT-style interface map

If this board eventually mates with a carrier, controller board, or a HAT-style board, this is the draft logic interface to preserve.

| Interface signal | Direction at matrix board | Voltage domain | Purpose | Status |
|---|---|---|---|---|
| `+3V3_LOGIC` | In | 3.3V | Logic reference / host side logic power | TBD |
| `+5V_SW` | In or local | 5V | Comparator supply domain | TBD |
| `GND` | Both | 0V | Shared reference | Required |
| `SR_SCLK` | In | 3.3V | Shift-register clock from controller | Draft |
| `SR_LATCH` | In | 3.3V | Shift-register latch from controller | Draft |
| `SR_DATA0` | In | 3.3V | Output pattern data | Draft |
| `SR_DATA1` | In | 3.3V | Optional second data path | Optional |
| `SR_OE_N` | In | 3.3V | Safe global output enable | Recommended |
| `SW_COL_0` | Out | 3.3V | Switch column readback | Draft |
| `SW_COL_1` | Out | 3.3V | Switch column readback | Draft |
| `SW_COL_2` | Out | 3.3V | Switch column readback | Draft |
| `SW_COL_3` | Out | 3.3V | Switch column readback | Draft |
| `UART_TX` | Out | 3.3V | Bring-up/debug serial | Recommended |
| `UART_RX` | In | 3.3V | Bring-up/debug serial | Recommended |
| `EN/RESET` | In | 3.3V | Reset or enable control | Optional |

## Board-mating notes
- keep **lamp power/current** off any small logic/HAT connector
- keep the logic/mating connector keyed and clearly mark **pin 1**
- group grounds near fast logic signals to reduce noise issues
- reserve at least one spare control line for future output enable / interrupt use
- document mating orientation early so schematic names and silkscreen stay consistent

## Open items to finalize
- choose the final connector family and pitch
- decide whether `SR_DATA1` remains useful or can be removed
- confirm whether the controller provides `+3V3_LOGIC`, or whether the board generates it locally
- define the exact row/column harness pin order before PCB routing
- confirm whether a HAT-style physical form factor is actually desired or if only a generic board-to-board header is needed

## Revision notes
- 2026-04-06: initial pinmap and board-mating draft added.

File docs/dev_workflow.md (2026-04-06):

# Solo Git Workflow (simple + Copilot-friendly)

Goal: keep `main` as "known good" while still doing messy bring-up work.

## Branches
- `main`:
  - Always buildable / readable
  - Contains only the code + schematic you would ship
- `bringup-*` branches:
  - Temporary test routines, prints, one-off experiments
  - Examples:
    - `bringup-switch-inputs`
    - `bringup-row-drivers`
    - `bringup-2026-04-06`

## Daily workflow (solo)
1. Create a branch before experiments
2. Commit small checkpoints often
3. When a block works:
   - merge back to `main` using **Squash merge** (clean history), or
   - cherry-pick only the "final" commits into `main`

## Why do this even solo?
- prevents "one giant file full of test junk"
- lets you keep a lab notebook history without polluting `main`
- makes it easier for Copilot (and future-you) to understand the project

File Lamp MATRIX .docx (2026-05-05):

We need a fundamental change how we are doing the scan . we need to be very determinalistic in the approach, So all 64 bits has it own time slice;

the biggest star of this operation is going to be the shift register and how we do that. The Update Shift Reg routine need to be a tight as possible because it the basic timing block. We need 4 updates to generate each pulse

Lamp_Data – array 4 columns and 8 rows ( bit array)

Switch_Data – array 4 columns and 8 rows ( bit array)

Shift Reg Data array - 16 bits (only 12 being used)

For Row= 1 to 8

For Column 1 to 9

If Current column < 4 // (lamps)

Read data array for lamps Lamp Data(row,col)

IF Lamp Data(row,col) =1 then pulse lamp on If not then continue to check next element

- Transfer current shift_registeter Data to set column active
- Set current row =on ( update shift reg )
- Delay for pulse width 2-5us // lamp Pulse width adjustment
- set row pin off // set all row pins off here (update shift reg)
- Transfer current shift_registeter Data to set all columns low // AND bits to turn o

IF current column < or = 4 then

- Transfer current shift_registeter Data to set column active
- Set current row pin =
- Delay for pulse width 2-5us // Pulse width adjustment
- Read Input data and store //
- set row pin off // set all row pins off here
- Transfer current shift_registeter Data to set all columns low // AND bits to turn off

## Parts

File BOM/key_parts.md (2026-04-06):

# Key Parts / BOM Notes

## Lamp row drivers (high-side)
- ST **VNQ7E100AJTR** (PowerSSO-16) — 4ch smart high-side switch
  - Qty: 2 (8 rows total)

### VNQ strap guidance (from datasheet snippets used in design)
- FaultRST: active low; keep low for auto-restart mode
- Unused connections:
  - SEn, SEL0, SEL1, FaultRST -> GND through 15k
  - CS -> GND through 1k

## Switch input conditioning
- Comparator: **LMV393** (dual), 5V supply, open-collector outputs
  - Qty: 2 (4 channels)
- Clamp diodes: **BAT54** dual Schottky (SOT-23) or equivalent
  - Qty: 4 (one per switch column)

## Shift registers (output expansion)
- **74HC595** @ 3.3V (or use 74HCT595 if powering at 5V)
  - Qty: 2

## Row output EMI parts (tuning)
- Ferrite bead (0805):
  - Murata **BLM21PG601SN1D** (600Ω @ 100MHz)
- Snubber (DNP by default):
  - R: 100Ω (footprint provided)
  - C: 1nF (footprint provided)

## Power entry
- TVS: (project-selected part)
- Fuse/PTC: current design target ~1.1A–1.85A hold equivalent (confirm after measurements)

## Test points / debug access
- Recommended small SMT debug test point style:
  - **Harwin S1751-46R** class SMT loop test point for low-current logic/debug nodes
- Alternate approach:
  - use simple labeled pogo pads where only fixture/probe access is needed
- Suggested use cases:
  - logic rails, reset, UART, shift-register control, switch-column outputs
- Avoid using tiny logic-style SMT test points for high-current lamp paths

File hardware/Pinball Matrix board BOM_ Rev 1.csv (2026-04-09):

Reference | Qty | Value | DNP | Exclude from BOM | Exclude from Board | LCSC | MANUFACTURER | Manufacturer_Part_Number | Part
10mm1 | 1 | ~ |  | Excluded from BOM
C1,C2,C3,C4,C6 | 5 | 47uF |  |  |  | C96123 |  |  | CL31A476MPHNNNE
C5,C12,C15,C17,C18,C19,C20,C21,C22,C23 | 10 | 100nF |  |  |  | C49678 |  |  | CC0805KRX7R9BB104
C7,C8,C9,C10,C26,C27,C28,C29,C30,C31,C32,C33 | 12 | 1nF |  |  |  | C46653 |  |  | CL21B102KBCNNNC
C11,C13,C14,C24,C25 | 5 | 1uF |  |  |  | C28323 |  |  | CL21B105KBFNNNE
C16 | 1 | 330uf |  |  |  | C122240
C34 | 1 | 100uF |  |  |  | C15008 |  |  | CL31A107MQHNNNE
D1 | 1 | H24VL10B |  |  |  | C20617912 |  |  | H24VL10B
D2 | 1 | H3V3LD5B |  |  |  | C20615817 |  |  | H3V3LD5B
D3,D9 | 2 | Green |  |  |  | C2297 |  |  | KT-0805G
D4 | 1 | Yellow |  |  |  | C2296 |  |  | KT-0805Y
D5,D6,D7,D8 | 4 | BAT54C,215 |  |  |  | C37704 |  |  | BAT54C,215
D10 | 1 | H5VND5B |  |  |  | C20615818 |  |  | H5VND5B
F1 | 1 | Polyfuse |  |  |  | C49166597
F2 | 1 | Polyfuse |  |  |  | C720075
FB1,FB2,FB3,FB4,FB5,FB6,FB7 | 7 | FerriteBead |  |  |  | C1015 |  |  | GZ2012D101TF
FB8 | 1 | FerriteBead |  |  |  | C1015 |  |  | GZ2012D101TF
H1,H2,H3 | 3 | MountingHole |  | Excluded from BOM
J1,J2 | 2 | B4B-XH-A |  |  |  |  | JST
J3 | 1 | Conn_01x13_Pin
J4 | 1 | Conn_01x10_Pin
L1,L2,L3,L4,L5 | 5 | IRLZ24 |  |  |  | C3007 |  | IRLZ44NPBF
R1,R2,R3,R4,R5,R6 | 6 | 4.7kΩ |  |  |  | C17673 |  |  | 0805W8F4701T5E
R7,R8,R9,R10 | 4 | 47kΩ |  |  |  | C17713 |  |  | 0805W8F4702T5E
R11,R17,R18,R19,R20,R30,R32,R34,R36,R38,R40,R42,R44,R48,R49,R50,R51,R52 | 18 | 220Ω |  |  |  | C17557 |  |  | 0805W8F2200T5E
R12 | 1 | 330Ω |  |  |  | C17630 |  |  | 0805W8F3300T5E
R13,R14,R15,R16,R25,R26,R27,R29,R53,R54,R55,R56,R57 | 13 | 10kΩ |  |  |  | C17414 |  |  | 0805W8F1002T5E
R21,R22,R23,R24,R31,R33,R35,R37,R39,R41,R43,R45 | 12 | 100kΩ |  |  |  | C149504 |  |  | 0805W8F1003T5E
R28 | 1 | 3kΩ |  |  |  | C17661 |  |  | 0805W8F3001T5E
R46,R47,R58,R60,R61,R63 | 6 | 15kΩ |  |  |  | C17475 |  |  | 0805W8F1502T5E
R59,R62 | 2 | 1kΩ |  |  |  | C17513 |  |  | 0805W8F1001T5E
R64,R65,R66,R67,R68,R69,R70,R71 | 8 | 100Ω |  |  |  | C17408 |  |  | 0805W8F1000T5E
TP1,TP2,TP3,TP4,TP5,TP6,TP7,TP8,TP9,TP11,TP12 | 11 | TestPoint_Small
TP10 | 1 | TestPoint
U1,U2 | 2 | LMV393 |  |  |  | C7984
U3 | 1 | ESP32-C6-DevKitM-Amazon |  | Excluded from BOM
U4,U5 | 2 | 74HC595D |  |  |  | C5947 |  |  | 74HC595D,118
U6,U7 | 2 | VNQ7E100AJTR |  |  |  | C2969931
U8 | 1 | OLED 256x128 |  | Excluded from BOM

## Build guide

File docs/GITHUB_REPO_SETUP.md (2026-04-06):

# GitHub Repo Setup Notes

This file captures the recommended GitHub-facing settings for the repository.

## Suggested repository description
`8x4 pinball lamp matrix driver and switch matrix scanner board using VNQ7E100AJTR, LMV393, 74HC595, and ESP32-C6.`

## Suggested topics
- `pinball`
- `electronics`
- `kicad`
- `pcb`
- `embedded`
- `esp32-c6`
- `platformio`
- `hardware-design`

## Suggested GitHub settings
- **Issues:** enabled
- **Projects:** optional
- **Discussions:** optional later
- **Wiki:** optional, probably leave off for now
- **Default branch:** `main`

## Community health files now in repo
- `CONTRIBUTING.md`
- `SECURITY.md`
- `.github/ISSUE_TEMPLATE/`
- `.github/pull_request_template.md`
- `.github/workflows/firmware-ci.yml`

## Notes
GitHub repo metadata such as the About text, website field, and topic tags are normally set from the GitHub web UI unless the GitHub CLI/API is configured locally.

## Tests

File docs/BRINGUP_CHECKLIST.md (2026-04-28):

# Rev 1 Bring-Up Checklist

Use this note when the first ordered boards arrive.

## Current status
- Rev 1 PCB, stencil, and parts were ordered on **2026-04-09**.
- Board was **assembled** and **5V + 3.3V rails confirmed up** on **2026-04-27**.
- Current project phase is **active bring-up** — logic validation and staged lamp testing.
- Goal for Rev 1 is **fast validation**, not perfection.

---

## 1) Assembly / visual inspection
- [x] Check orientation of diodes, TVS parts, polarized caps, connectors, and the ESP32 board/module
- [x] Inspect `VNQ7E100AJTR` thermal pad soldering and general stencil results
- [x] Look for solder bridges, tombstones, lifted pads, or missing passives
- [x] Verify connector labels and pin 1 direction before attaching harnesses

## 2) Pre-power continuity checks
- [x] Check resistance / continuity between `18V` and `GND`
- [x] Check resistance / continuity between `5V` and `GND`
- [x] Check resistance / continuity between `3.3V` and `GND`
- [x] Confirm fuse / TVS placement matches the schematic

## 3) First power-up
- [x] Use current limiting if possible
- [x] Bring up the supply and verify `5V` rail first ✓ **5V confirmed 2026-04-27**
- [x] Verify `3.3V` regulator / logic rail is correct ✓ **3.3V confirmed 2026-04-27**
- [ ] Confirm the ESP32-C6 boots and the bring-up firmware still runs
- [ ] Verify no unexpected heating on regulators, VNQs, or protection parts

## 4) Logic validation
- [ ] Confirm shift-register clock / latch / data activity
- [x] Confirm `/OE` behaves safely at boot (`SR_/OE` on GPIO10, driven low to enable outputs)
- [x] Read all four switch-column outputs and compare with expected states
- [ ] Probe key debug test points as needed
- [x] In serial monitor run switch bring-up mode and verify:
	- `Runtime mode: SWITCH_SCAN ...`
	- `HB ...`
	- `SWITCH_SCAN row=... hits[rX]=...`
	- `SW_EDGE/s: ...`

## 5) Lamp-path validation
- [ ] Confirm lamp tests are explicitly armed first: `ARM ON`
- [ ] Test one lamp row and one lamp column first
- [ ] Confirm the expected row/column energizing pattern
- [ ] Then run a full matrix scan at low risk / supervised conditions
- [ ] Watch connector temperature, trace heating, and supply sag during testing
- [ ] End with safe shutdown command sequence: `ALLOFF` then `ARM OFF`

## 6) Capture results
- [ ] Record any polarity, routing, thermal, or noise surprises
- [ ] Note which DNP / tuning parts should become default-fit later
- [ ] Update `docs/NEXT_ITERATION.md` and `docs/PROJECT_STATUS.md` with findings
- [ ] Open a Rev 2 checklist if hardware testing shows needed changes

## 7) 2026-04-28 checkpoint
- [x] Lamp side hardware path validated enough for controlled attract testing
- [x] Found/adjusted swapped gate resistor placement on 3 of 4 lamp columns during bench debug
- [x] Added low-duty attract chase routine in firmware for brightness/mapping checks
- [x] Added dedicated switch scan mode (`kRuntimeMode = RuntimeMode::SwitchScan`) for row-by-row switch input verification
- [x] Verified firmware prints switch diagnostics (`SWITCH_SCAN`, `SW_EDGE/s`) on live board
- [ ] Use known-good bulbs to isolate possible burnt lamp bulbs from circuit faults
- [ ] Finalize clamp diode part choice at comparator input stage (`BAT54S` style clamp preferred for signal-to-rails)

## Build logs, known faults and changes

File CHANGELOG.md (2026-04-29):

# Changelog

All notable changes to this project will be documented in this file.

The format follows a simple **Keep a Changelog** style.

## [Unreleased]
### Added
- Structured three-phase bring-up firmware: walking-1 SR test, switch-column poll with change detection, one-row/one-column lamp test, then continuous SW monitor
- `docs/MACHINE_TRANSFER_HANDOFF_2026-04-27.md` added for session resume
- Command-driven bring-up console with explicit lamp arming (`ARM ON|OFF`) and operator-invoked tests (`WALK`, `SWPOLL`, `LAMP`, `ALLOFF`)
- Low-duty attract-style lamp chase sequence for matrix brightness/mapping validation
- Dedicated `RuntimeMode::SwitchScan` firmware path with row-driven scan and per-row switch hit counters
- Switch edge-rate telemetry (`SW_EDGE/s`) and control-link telemetry (`CTRL_I2C edges/s`) included in heartbeat output
- `RuntimeMode::I2cSlaveRegmap` path for matrix control-link integration at I2C address `0x24`
- Register-backed slave handling for lamp rows (`0x00..0x07`), switch bytes (`0x40..0x43`), and diagnostics (`0xF0..0xF3`)
- OLED rendering retained in slave mode via software I2C on `GPIO7/GPIO6`
- On-device OLED layout with status banner, 8x5 matrix grid, and right-pane telemetry (sweep/trace)
- Link-state display and detection states: `WAIT`, `LIVE`, and `DEGRADED` (TX-stall aware)

### Changed
- `docs/PROJECT_STATUS.md` updated: 5V and 3.3V rails confirmed up; phase is now active bring-up
- `docs/BRINGUP_CHECKLIST.md`: assembly, continuity, and first power-up items marked complete
- `docs/NEXT_ITERATION.md`: active bring-up focus noted; Rev 2 trace-width note added (0805 pads → ~1.5 mm)
- `firmware/src/main.cpp` refactored from simple walking-1 loop into three explicit bring-up phases with labelled console output
- `firmware/src/main.cpp` now defaults to safe idle with outputs off and requires explicit operator command before lamp-path testing
- `firmware/src/main.cpp` now supports mode-selectable bring-up runtime with `SwitchScan` default for switch validation focus
- `firmware/README.md` updated with current validated pin map, runtime modes, and no-space build-path guidance
- `firmware/src/main.cpp` now defaults to `RuntimeMode::I2cSlaveRegmap` for control-board integration bring-up
- I2C telemetry counters split into `badWrites` vs `ignoredWrites` for clearer protocol diagnostics

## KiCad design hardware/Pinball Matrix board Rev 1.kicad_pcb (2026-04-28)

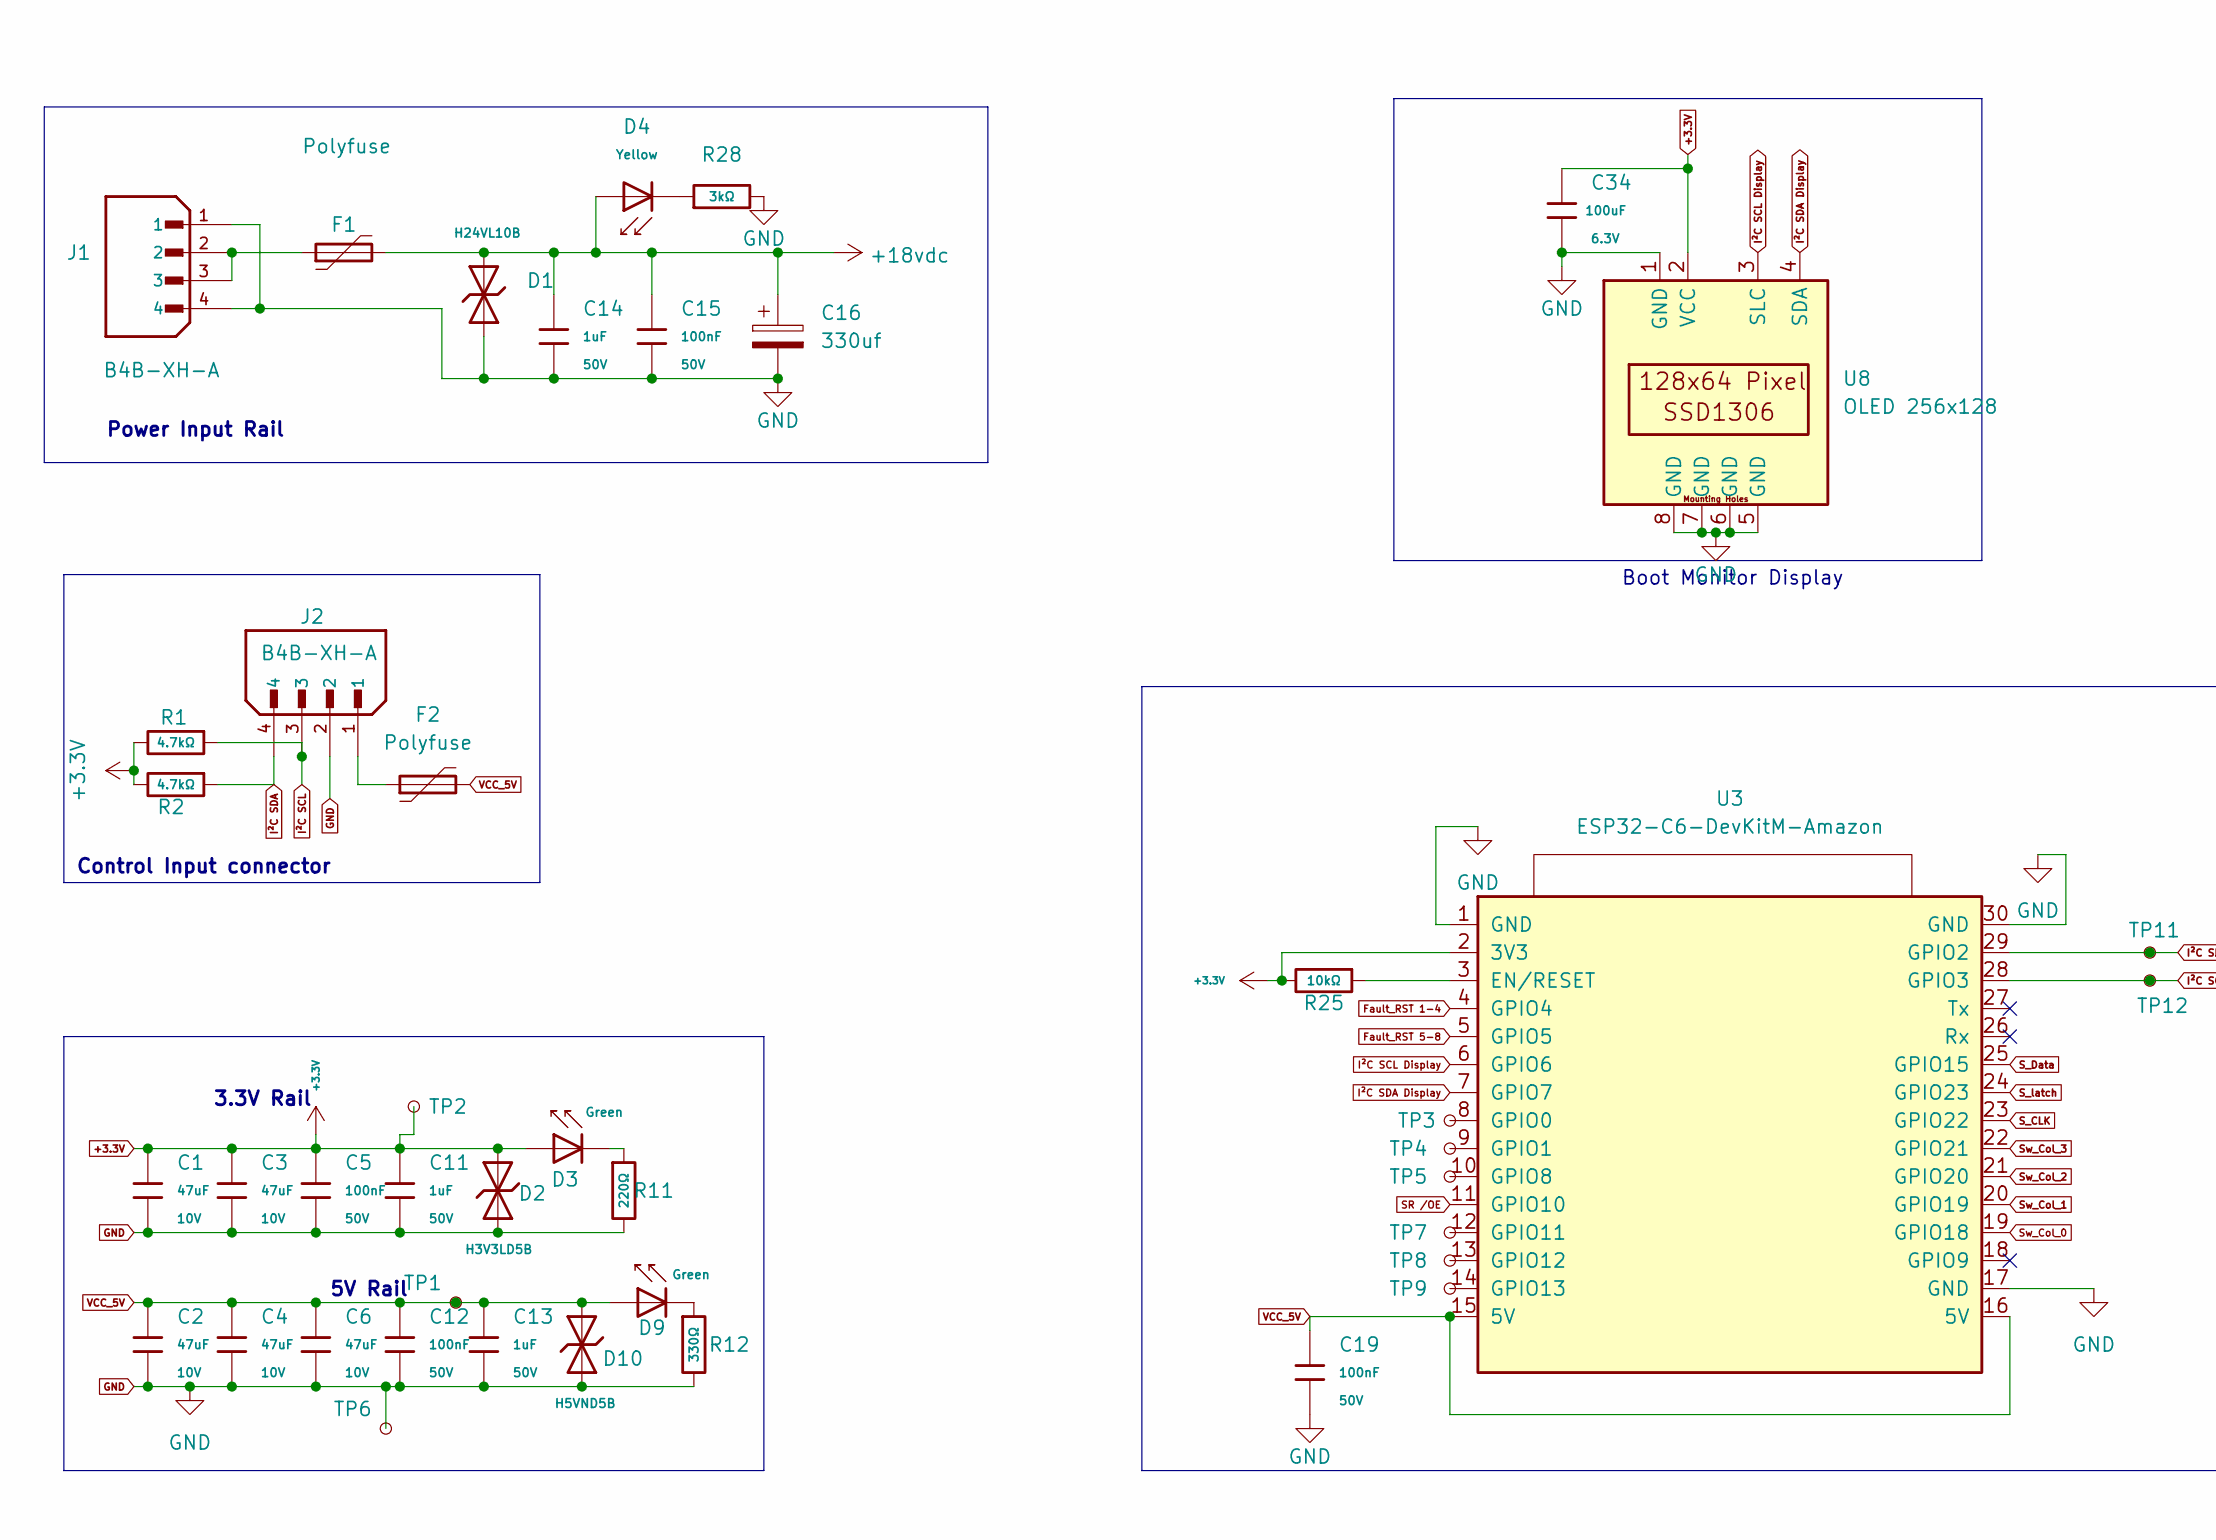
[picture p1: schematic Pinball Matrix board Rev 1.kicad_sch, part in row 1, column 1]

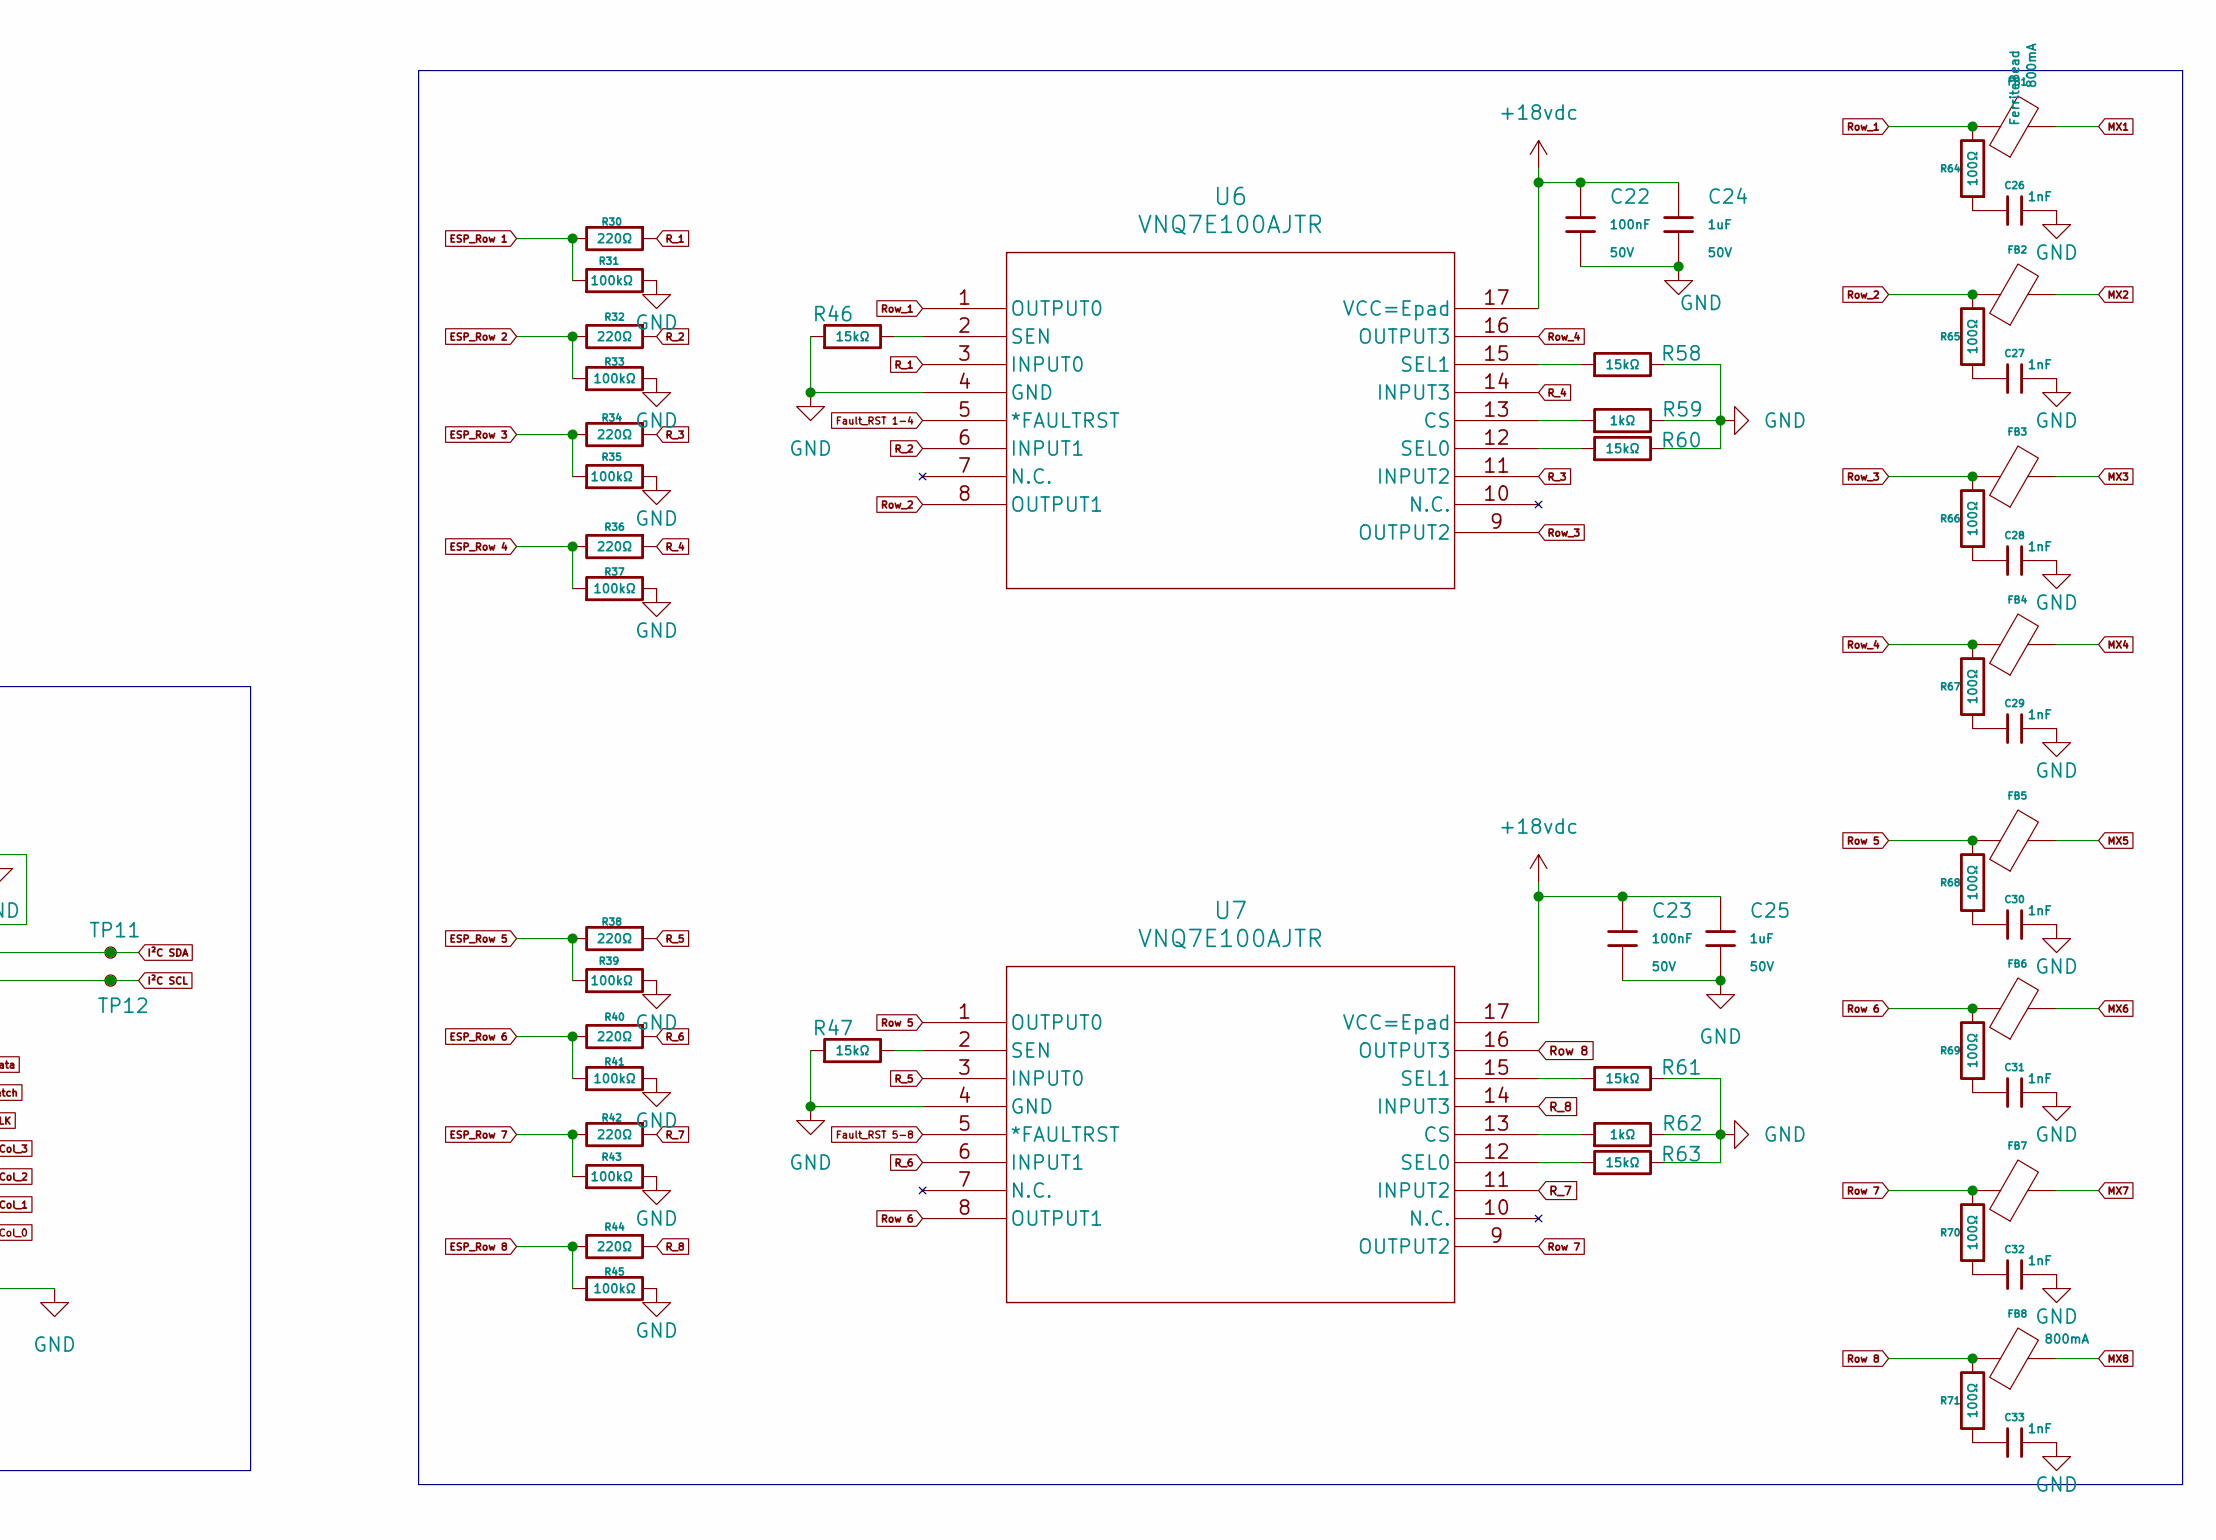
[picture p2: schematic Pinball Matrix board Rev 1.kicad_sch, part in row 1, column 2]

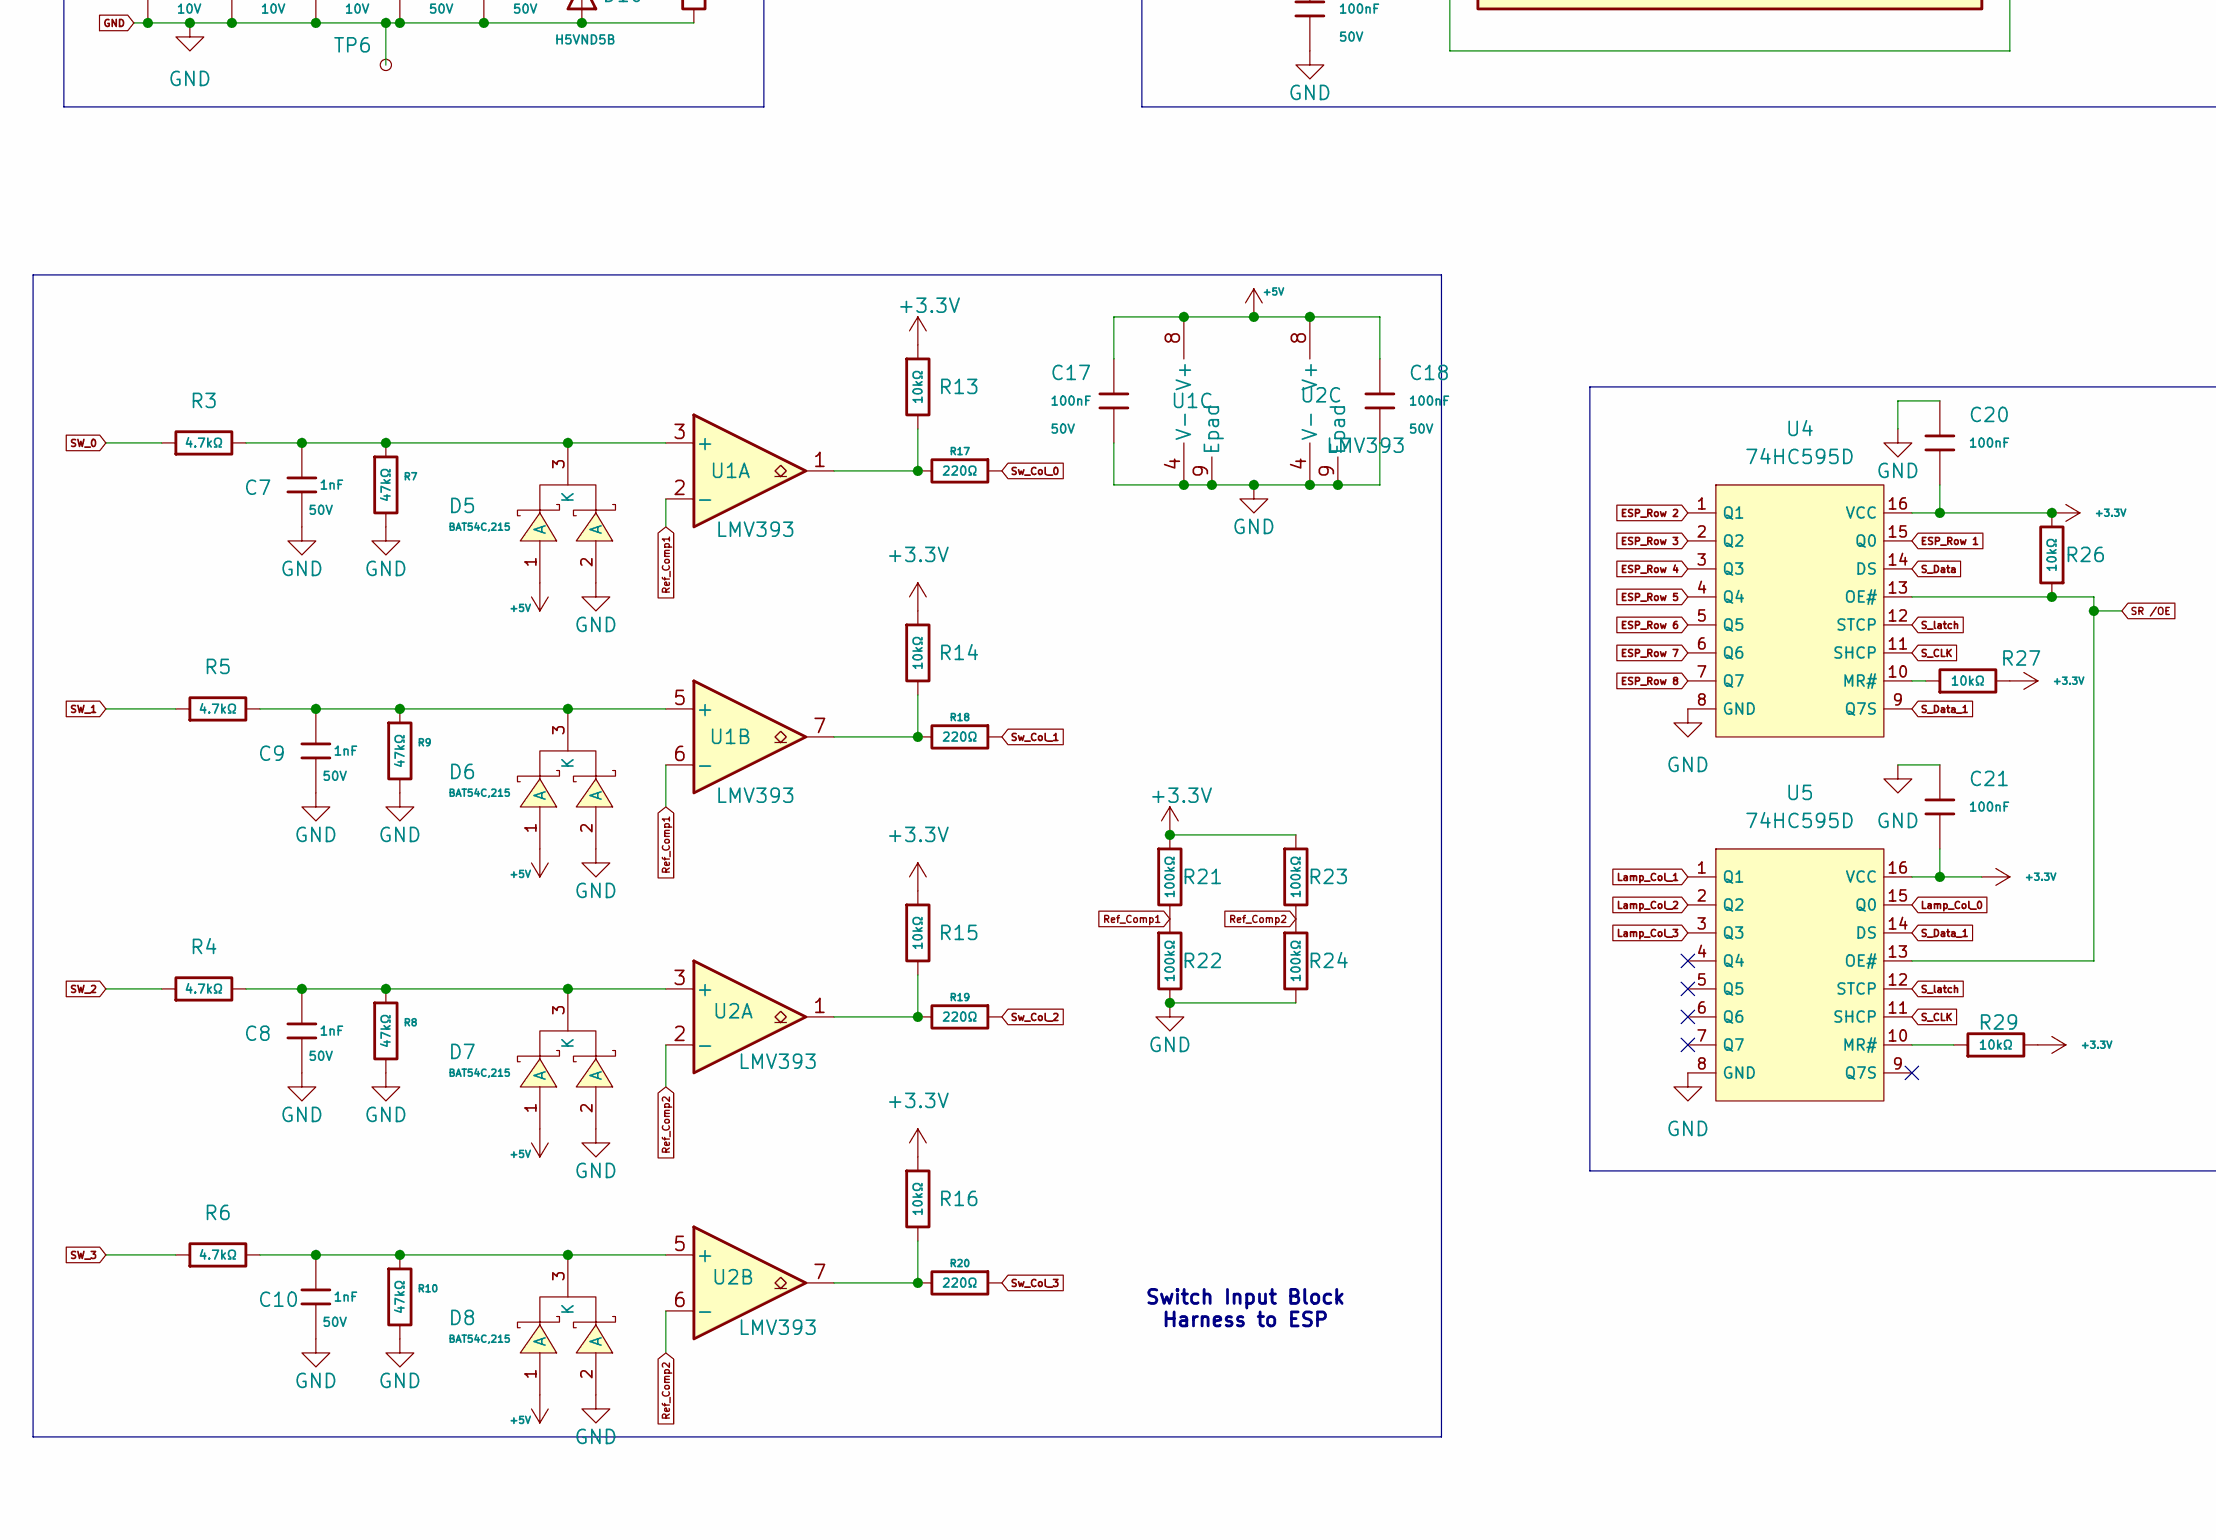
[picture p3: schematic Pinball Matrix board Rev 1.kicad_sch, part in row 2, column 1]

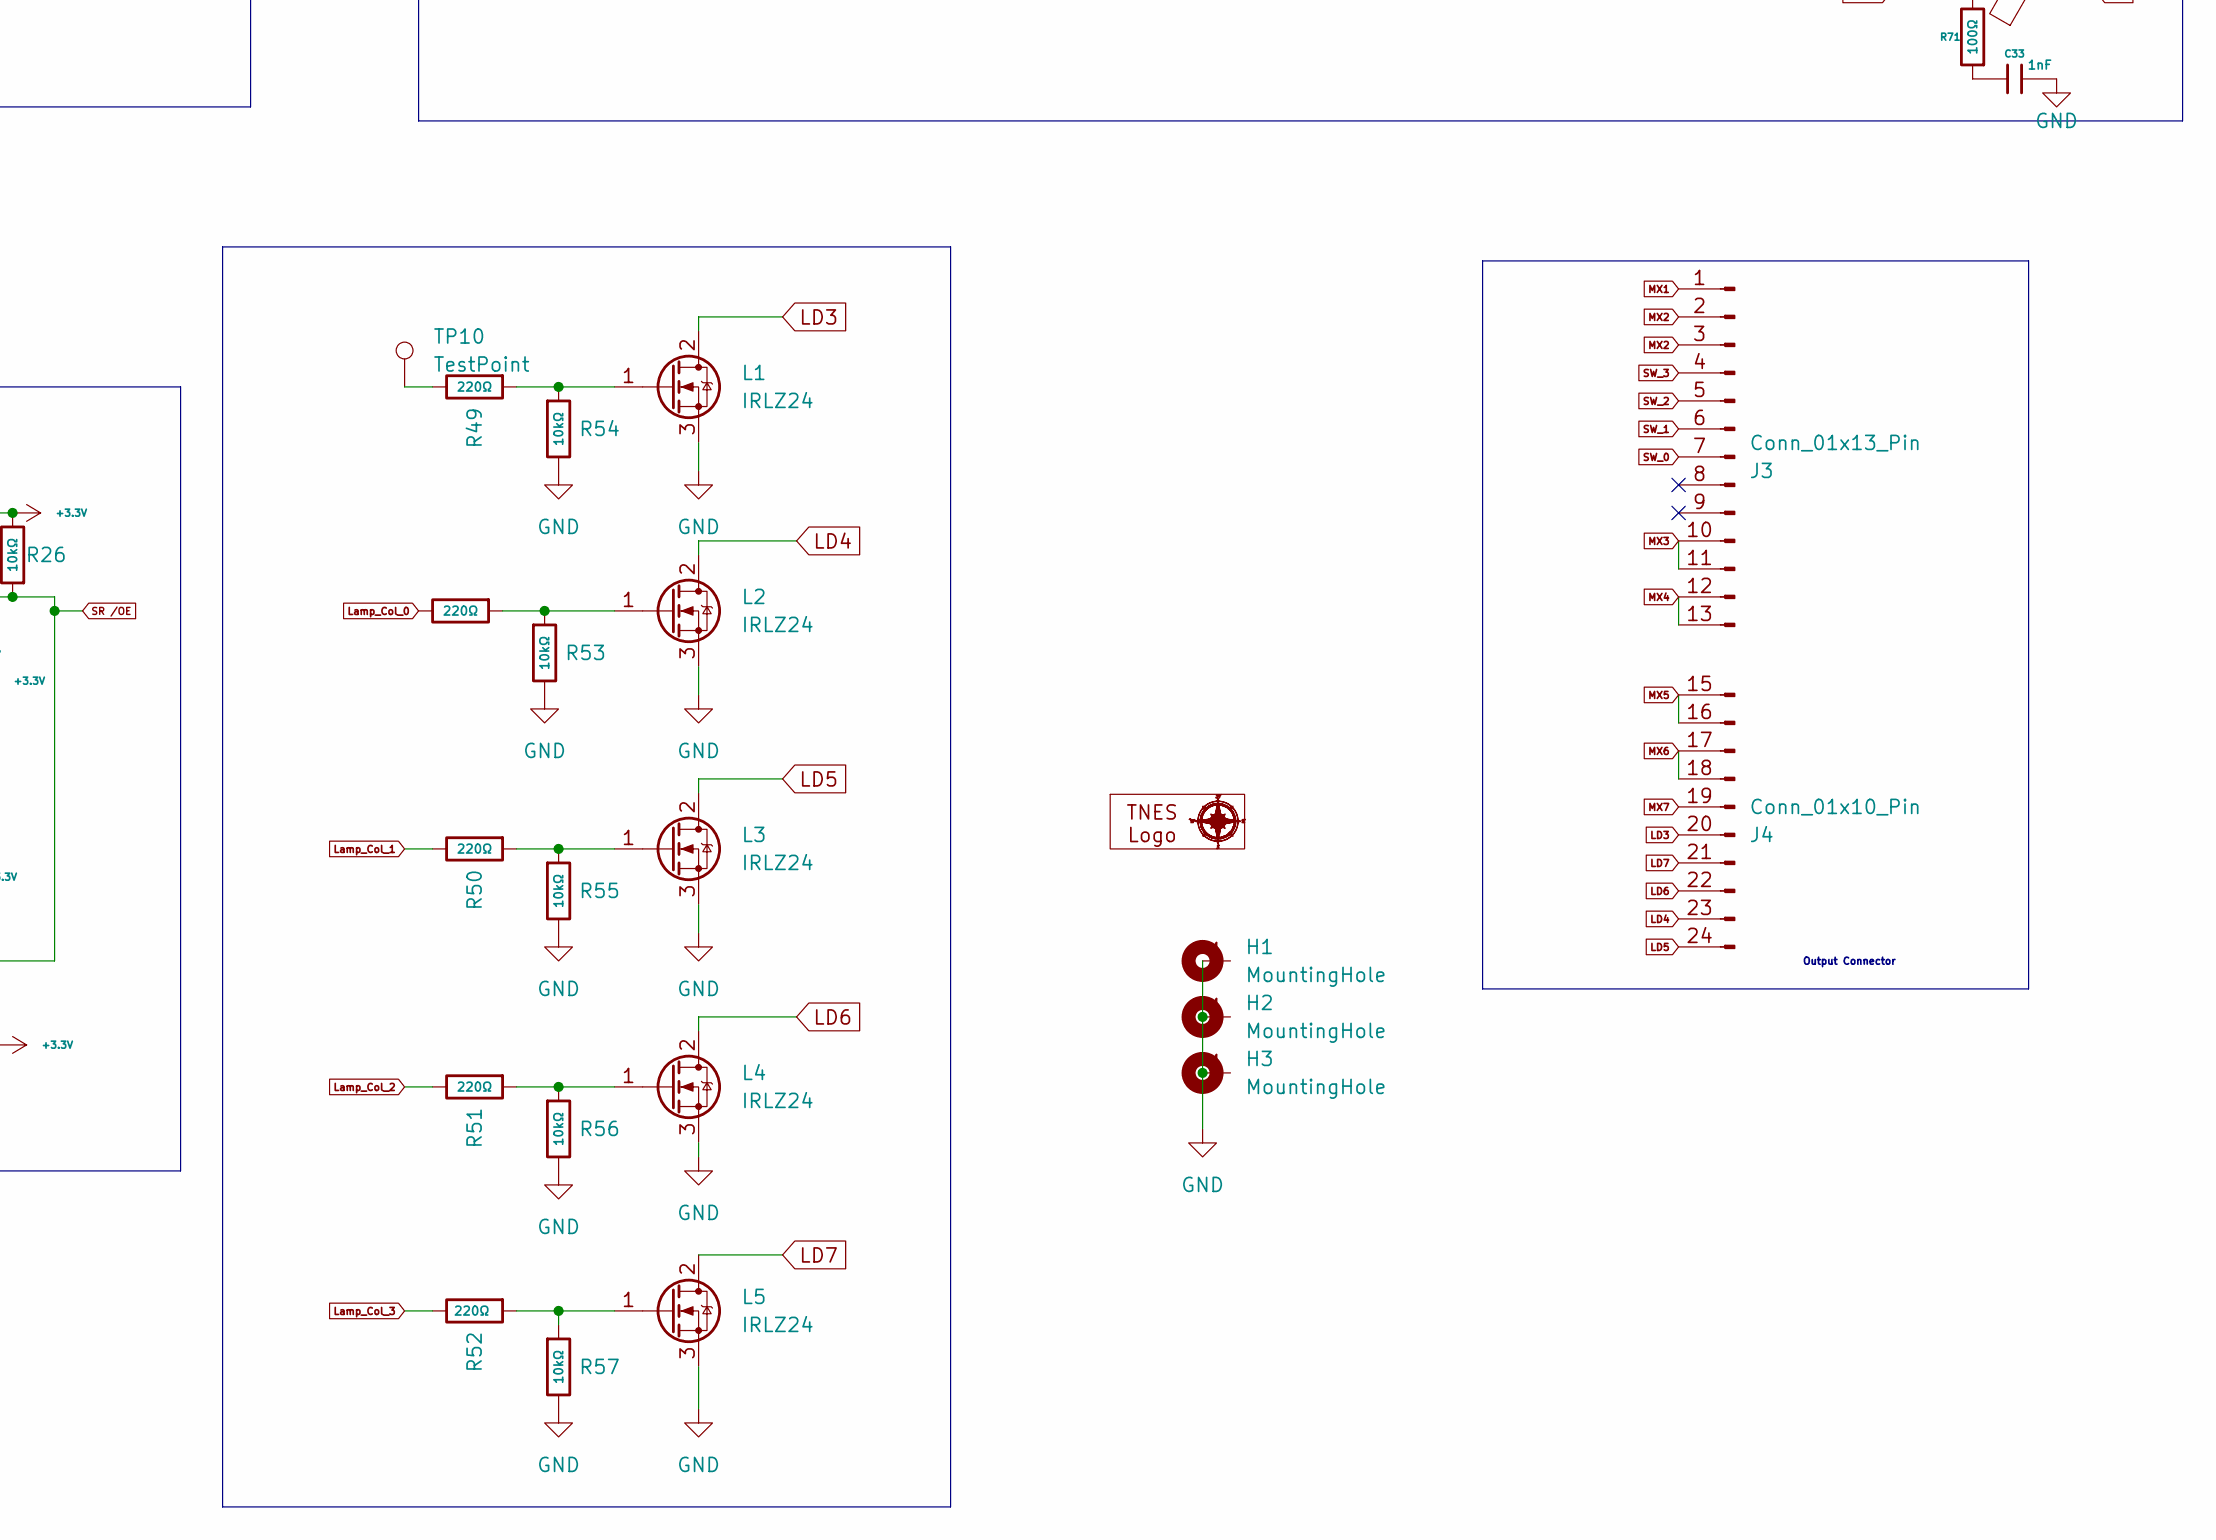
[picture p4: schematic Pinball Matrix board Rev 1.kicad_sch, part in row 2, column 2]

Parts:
10mm1: 10mm LOGO
C1, C2, C3, C4, C6: 47uF; C_1206; Voltage Rated 10V; Tolerance ±20%; Part CL31A476MPHNNNE; LCSC C96123
C5, C12, C15, C17, C18, C19, C20, C21, C22, C23: 100nF; C_0805; Voltage Rated 50V; Tolerance ±10%; Part CC0805KRX7R9BB104; LCSC C49678
C7, C8, C9, C10, C26, C27, C28, C29, C30, C31, C32, C33: 1nF; C_0805; Voltage Rated 50V; Tolerance ±10%; Part CL21B102KBCNNNC; LCSC C46653
C11, C13, C14, C24, C25: 1uF; C_0805; Voltage Rated 50V; Tolerance ±10%; Part CL21B105KBFNNNE; LCSC C28323
C16: 330uf; CP_Radial_D6.3mm_P2.50mm; LCSC C122240
C34: 100uF; C_1206; Voltage Rated 6.3V; Tolerance ±20%; Part CL31A107MQHNNNE; LCSC C15008
D1: H24VL10B; D_DFN1006-2L; Part H24VL10B; LCSC C20617912
D2: H3V3LD5B; D_SOD-523; Breakdown Voltage 5.5V; Part H3V3LD5B; LCSC C20615817
D3, D9: Green; D_0805; Part KT-0805G; LCSC C2297
D4: Yellow; D_0805; Part KT-0805Y; LCSC C2296
D5, D6, D7, D8: BAT54C,215; SOT-23-3_L2.9-W1.6-P1.90-LS2.8-BR; Reverse Voltage (Vr) 30V; Forward Voltage (Vf@If) 800mV@100mA; Part BAT54C,215; LCSC C37704
D10: H5VND5B; D_SOD-523; Part H5VND5B; LCSC C20615818
F1: Polyfuse; poly fuse; LCSC C49166597
F2: Polyfuse; L_1206; LCSC C720075
FB1, FB2, FB3, FB4, FB5, FB6, FB7: FerriteBead; L_1206; Current Rating 800mA; Tolerance ±25%; Part GZ2012D101TF; LCSC C1015
FB8: FerriteBead; FB_0805; Current Rating 800mA; Tolerance ±25%; Part GZ2012D101TF; LCSC C1015
H1, H2, H3: MountingHole; MountingHole_3.5mm_Pad
J1, J2: B4B-XH-A; JST_EH_B4B-EH-A_1x04_P2.50mm_Vertical; PARTREV 7/4/21
J3: Conn_01x13_Pin; Molex_KK-396_A-41791-0013_1x13_P3.96mm_Vertical
J4: Conn_01x10_Pin; Molex_KK-396_A-41791-0010_1x10_P3.96mm_Vertical
L1: IRLZ24; TO-252-2; Manufacturer_Part_Number IRLZ44NPBF; LCSC C3007
L2, L3, L4, L5: IRLZ24; TO-252-2; Mouser Part Number 942-IRLZ44NPBF
R1, R2, R3, R4, R5, R6: 4.7kΩ; R_0805; Overload Voltage (Max) 150V; Tolerance ±1%; Part 0805W8F4701T5E; LCSC C17673
R7, R8, R9, R10: 47kΩ; R_0805; Overload Voltage (Max) 150V; Tolerance ±1%; Part 0805W8F4702T5E; LCSC C17713
R11, R17, R18, R19, R20, R30, R32, R34, R36, R38, R40, R42, R44, R48, R49, R50, R51, R52: 220Ω; R_0805; Overload Voltage (Max) 150V; Tolerance ±1%; Part 0805W8F2200T5E; LCSC C17557
R12: 330Ω; R_0805; Overload Voltage (Max) 150V; Tolerance ±1%; Part 0805W8F3300T5E; LCSC C17630
R13, R14, R15, R16, R25, R26, R27, R29, R53, R54, R55, R56, R57: 10kΩ; R_0805; Overload Voltage (Max) 150V; Tolerance ±1%; Part 0805W8F1002T5E; LCSC C17414
R21, R22, R23, R24, R31, R33, R35, R37, R39, R41, R43, R45: 100kΩ; R_0805; Overload Voltage (Max) 150V; Tolerance ±1%; Part 0805W8F1003T5E; LCSC C149504
R28: 3kΩ; R_0805; Overload Voltage (Max) 150V; Tolerance ±1%; Part 0805W8F3001T5E; LCSC C17661
R46, R47, R58, R60, R61, R63: 15kΩ; R_0805; Overload Voltage (Max) 150V; Tolerance ±1%; Part 0805W8F1502T5E; LCSC C17475
R59, R62: 1kΩ; R_0805; Overload Voltage (Max) 150V; Tolerance ±1%; Part 0805W8F1001T5E; LCSC C17513
R64, R65, R66, R67, R68, R69, R70, R71: 100Ω; R_0805; Overload Voltage (Max) 150V; Tolerance ±1%; Part 0805W8F1000T5E; LCSC C17408
TP1, TP2, TP3, TP4, TP5, TP6, TP7, TP8, TP9, TP11, TP12: TestPoint_Small; KEYSTONE_5015
TP10: TestPoint; PinSocket_1x01_P2.54mm_Vertical
U1, U2: LMV393; SOIC-8-1EP_3.9x4.9mm_P1.27mm_EP2.29x3mm; LCSC C7984
U3: ESP32-C6-DevKitM-Amazon; ESP32-C6-DevKit-Amazon
U4, U5: 74HC595D; SOIC-16_L9.9-W3.9-P1.27-LS6.0-BL; Supply Voltage 2V~6V; Part 74HC595D,118; LCSC C5947
U6, U7: VNQ7E100AJTR; SOP50P600X148-17N; LCSC C2969931
U8: OLED 256x128; 0.96 inOLED display SSD1306

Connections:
+3.3V: C1.1, C3.1, C5.1, C11.1, C20.2, C21.2, C34.1, D2.2, D3.2, R1.2, R2.2, R13.1, R14.1, R15.1, R16.1, R21.1, R23.1, R25.2, R26.2, R27.2, R29.2, TP2.1, U3.2 (3V3), U4.16 (VCC), U5.16 (VCC), U8.2 (VCC)
+5V: C17.1, C18.1, D5.1 (A), D6.1 (A), D7.1 (A), D8.1 (A), U1.8 (V+), U2.8 (V+)
+18vdc: C14.1, C15.1, C16.1, C22.1, C23.1, C24.1, C25.1, D1.2, D4.2, F1.2, U6.17 (VCC=Epad), U7.17 (VCC=Epad)
ESP_Row 1: R30.2, R31.1, U4.15 (Q0)
ESP_Row 2: R32.2, R33.1, U4.1 (Q1)
ESP_Row 3: R34.2, R35.1, U4.2 (Q2)
ESP_Row 4: R36.2, R37.1, U4.3 (Q3)
ESP_Row 5: R38.2, R39.1, U4.4 (Q4)
ESP_Row 6: R40.2, R41.1, U4.5 (Q5)
ESP_Row 7: R42.2, R43.1, U4.6 (Q6)
ESP_Row 8: R44.2, R45.1, U4.7 (Q7)
Fault_RST 1-4: U3.4 (GPIO4), U6.5 (*FAULTRST)
Fault_RST 5-8: U3.5 (GPIO5), U7.5 (*FAULTRST)
GND: C1.2, C2.2, C3.2, C4.2, C5.2, C6.2, C7.2, C8.2, C9.2, C10.2, C11.2, C12.2, C13.2, C14.2, C15.2, C16.2, C17.2, C18.2, C19.2, C20.1, C21.1, C22.2, C23.2, C24.2, C25.2, C26.2, C27.2, C28.2, C29.2, C30.2, C31.2, C32.2, C33.2, C34.2, D1.1, D2.1, D5.2 (A), D6.2 (A), D7.2 (A), D8.2 (A), D10.1, H1.1, H2.1, H3.1, J1.1, J1.4, J2.2, L1.3 (S), L2.3 (S), L3.3 (S), L4.3 (S), L5.3 (S), R7.2, R8.2, R9.2, R10.2, R11.2, R12.2, R22.2, R24.2, R28.2, R31.2, R33.2, R35.2, R37.2, R39.2, R41.2, R43.2, R45.2, R46.1, R47.1, R53.2, R54.2, R55.2, R56.2, R57.2, R58.2, R59.2, R60.2, R61.2, R62.2, R63.2, TP6.1, U1.4 (V-), U1.9 (Epad), U2.4 (V-), U2.9 (Epad), U3.1 (GND), U3.17 (GND), U3.30 (GND), U4.8 (GND), U5.8 (GND), U6.4 (GND), U7.4 (GND), U8.1 (GND), U8.5 (GND), U8.6 (GND), U8.7 (GND), U8.8 (GND)
I²C SCL: J2.3, R1.1, TP12.1, U3.28 (GPIO3)
I²C SCL Display: U3.6 (GPIO6), U8.3 (SLC)
I²C SDA: J2.4, R2.1, TP11.1, U3.29 (GPIO2)
I²C SDA Display: U3.7 (GPIO7), U8.4 (SDA)
LD3: J4.20 (Pin_6), L1.2 (D)
LD4: J4.23 (Pin_9), L2.2 (D)
LD5: J4.24 (Pin_10), L3.2 (D)
LD6: J4.22 (Pin_8), L4.2 (D)
LD7: J4.21 (Pin_7), L5.2 (D)
Lamp_Col_0: R48.2, U5.15 (Q0)
Lamp_Col_1: R50.2, U5.1 (Q1)
Lamp_Col_2: R51.2, U5.2 (Q2)
Lamp_Col_3: R52.2, U5.3 (Q3)
MX1: FB1.2, J3.1
MX2: FB2.2, J3.2, J3.3
MX3: FB3.2, J3.10, J3.11
MX4: FB4.2, J3.12, J3.13
MX5: FB5.2, J4.15 (Pin_1), J4.16 (Pin_2)
MX6: FB6.2, J4.17 (Pin_3), J4.18 (Pin_4)
MX7: FB7.2, J4.19 (Pin_5)
unnamed: C26.1, R64.1
unnamed: C27.1, R65.1
unnamed: C28.1, R66.1
unnamed: C29.1, R67.1
unnamed: C30.1, R68.1
unnamed: C31.1, R69.1
unnamed: C32.1, R70.1
unnamed: C33.1, R71.1
unnamed: D3.1, R11.1
unnamed: D4.1, R28.1
unnamed: C7.1, D5.3 (K), R3.2, R7.1, U1.3 (+)
unnamed: C9.1, D6.3 (K), R5.2, R9.1, U1.5 (+)
unnamed: C8.1, D7.3 (K), R4.2, R8.1, U2.3 (+)
unnamed: C10.1, D8.3 (K), R6.2, R10.1, U2.5 (+)
unnamed: D9.1, R12.1
unnamed: F1.1, J1.2, J1.3
unnamed: F2.1, J2.1
unnamed: L1.1 (G), R49.1, R54.1
unnamed: L2.1 (G), R48.1, R53.1
unnamed: L3.1 (G), R50.1, R55.1
unnamed: L4.1 (G), R51.1, R56.1
unnamed: L5.1 (G), R52.1, R57.1
unnamed: R13.2, R17.2, U1.1
unnamed: R14.2, R18.2, U1.7
unnamed: R15.2, R19.2, U2.1
unnamed: R16.2, R20.2, U2.7
unnamed: R49.2, TP10.1
unnamed: R25.1, U3.3 (EN/RESET)
unnamed: TP3.1, U3.8 (GPIO0)
unnamed: TP4.1, U3.9 (GPIO1)
unnamed: TP5.1, U3.10 (GPIO8)
unnamed: TP7.1, U3.12 (GPIO11)
unnamed: TP8.1, U3.13 (GPIO12)
unnamed: TP9.1, U3.14 (GPIO13)
unnamed: R27.1, U4.10 (MR#)
unnamed: R29.1, U5.10 (MR#)
unnamed: R59.1, U6.13 (CS)
unnamed: R60.1, U6.12 (SEL0)
unnamed: R58.1, U6.15 (SEL1)
unnamed: R46.2, U6.2 (SEN)
unnamed: R62.1, U7.13 (CS)
unnamed: R63.1, U7.12 (SEL0)
unnamed: R61.1, U7.15 (SEL1)
unnamed: R47.2, U7.2 (SEN)
R_1: R30.1, U6.3 (INPUT0)
R_2: R32.1, U6.6 (INPUT1)
R_3: R34.1, U6.11 (INPUT2)
R_4: R36.1, U6.14 (INPUT3)
R_5: R38.1, U7.3 (INPUT0)
R_6: R40.1, U7.6 (INPUT1)
R_7: R42.1, U7.11 (INPUT2)
R_8: R44.1, U7.14 (INPUT3)
Ref_Comp1: R21.2, R22.1, U1.2 (-), U1.6 (-)
Ref_Comp2: R23.2, R24.1, U2.2 (-), U2.6 (-)
Row 5: FB5.1, R68.2, U7.1 (OUTPUT0)
Row 6: FB6.1, R69.2, U7.8 (OUTPUT1)
Row 7: FB7.1, R70.2, U7.9 (OUTPUT2)
Row 8: FB8.1, R71.2, U7.16 (OUTPUT3)
Row_1: FB1.1, R64.2, U6.1 (OUTPUT0)
Row_2: FB2.1, R65.2, U6.8 (OUTPUT1)
Row_3: FB3.1, R66.2, U6.9 (OUTPUT2)
Row_4: FB4.1, R67.2, U6.16 (OUTPUT3)
SR /OE: R26.1, U3.11 (GPIO10), U4.13 (OE#), U5.13 (OE#)
SW_0: J3.7, R3.1
SW_1: J3.6, R5.1
SW_2: J3.5, R4.1
SW_3: J3.4, R6.1
S_CLK: U3.23 (GPIO22), U4.11 (SHCP), U5.11 (SHCP)
S_Data: U3.25 (GPIO15), U4.14 (DS)
S_Data_1: U4.9 (Q7S), U5.14 (DS)
S_latch: U3.24 (GPIO23), U4.12 (STCP), U5.12 (STCP)
Sw_Col_0: R17.1, U3.19 (GPIO18)
Sw_Col_1: R18.1, U3.20 (GPIO19)
Sw_Col_2: R19.1, U3.21 (GPIO20)
Sw_Col_3: R20.1, U3.22 (GPIO21)
VCC_5V: C2.1, C4.1, C6.1, C12.1, C13.1, C19.1, D9.2, D10.2, F2.2, TP1.1, U3.15 (5V), U3.16 (5V)

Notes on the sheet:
Boot Monitor Display
5V Rail
Switch Input Block Harness to ESP
Output Connector
3.3V Rail
Power Input Rail
Control Input connector

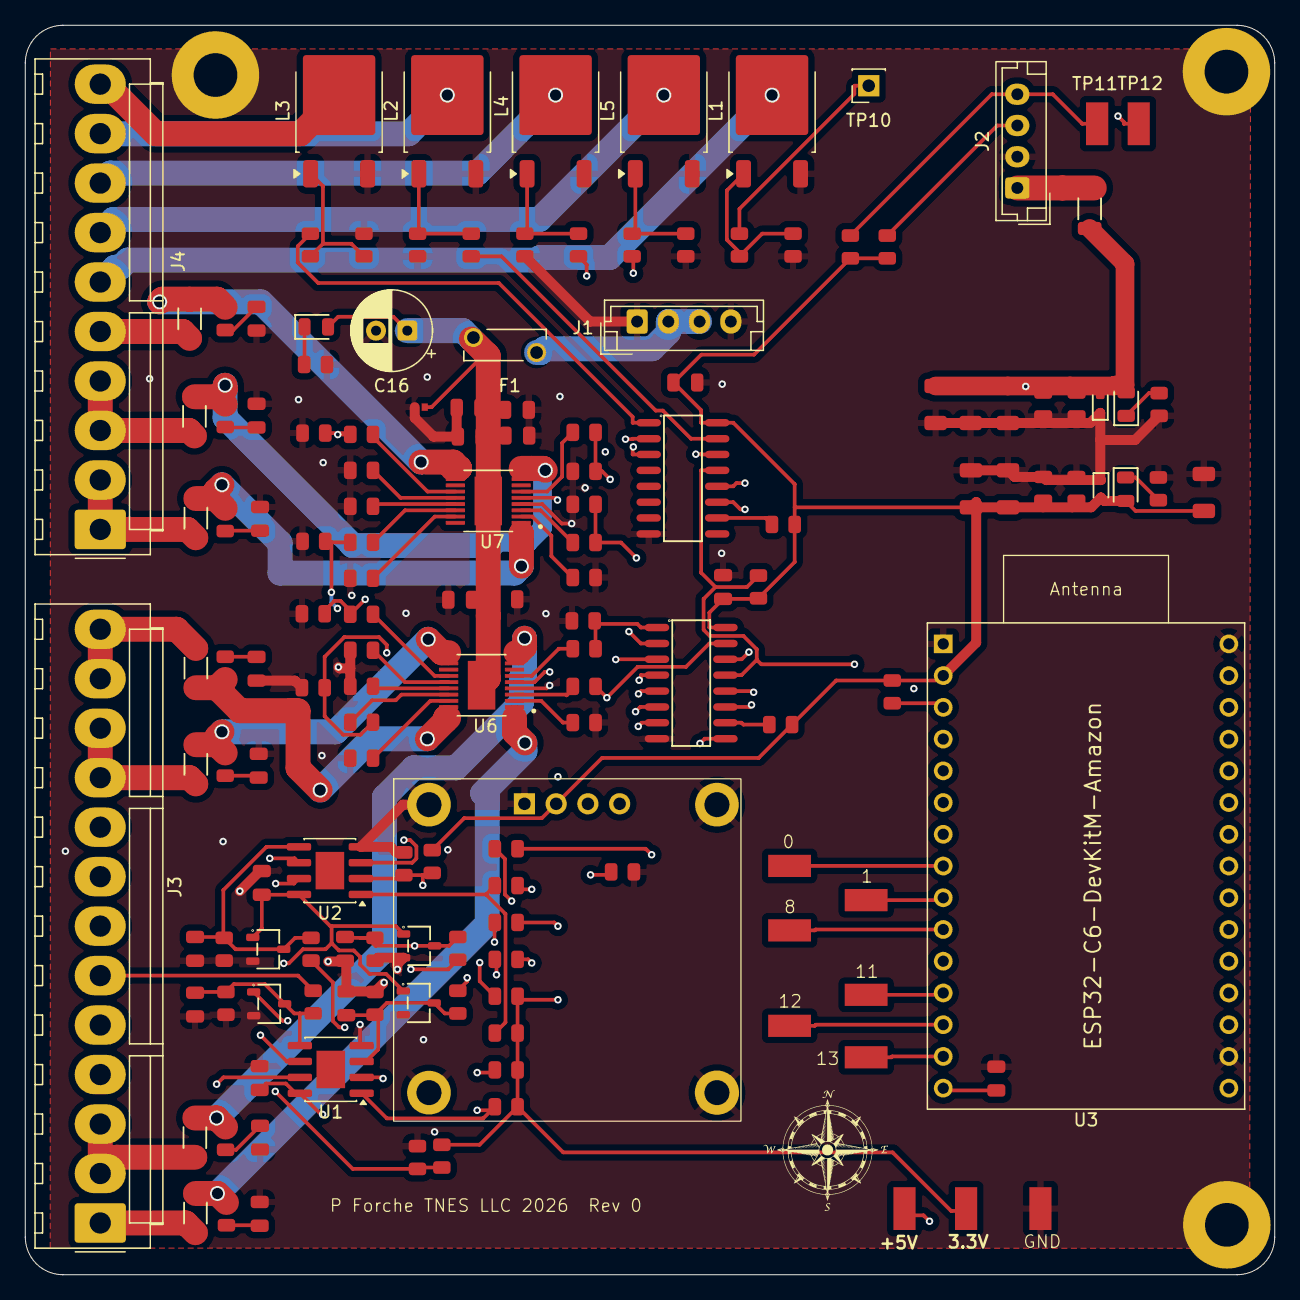
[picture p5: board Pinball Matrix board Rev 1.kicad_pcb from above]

Board: 4 copper layers, 100.0 x 100.0 mm, 155 parts (0 on the bottom side), 108 nets.

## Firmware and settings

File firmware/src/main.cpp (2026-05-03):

#include <cstdio>
#include <cstdint>
#include <cstring>

#include "driver/gpio.h"
#include "driver/i2c.h"
#include "driver/i2c_master.h"
#include "esp_err.h"
#include "esp_check.h"
#include "esp_rom_sys.h"
#include "esp_timer.h"
#include "freertos/FreeRTOS.h"
#include "freertos/task.h"

static constexpr gpio_num_t PIN_SW_COL0 = GPIO_NUM_18;
static constexpr gpio_num_t PIN_SW_COL1 = GPIO_NUM_19;
static constexpr gpio_num_t PIN_SW_COL2 = GPIO_NUM_20;
static constexpr gpio_num_t PIN_SW_COL3 = GPIO_NUM_21;

static constexpr gpio_num_t PIN_SR_DATA  = GPIO_NUM_15;
static constexpr gpio_num_t PIN_SR_CLK   = GPIO_NUM_22;
static constexpr gpio_num_t PIN_SR_LATCH = GPIO_NUM_23;
static constexpr gpio_num_t PIN_SR_OE_N  = GPIO_NUM_10;

static constexpr gpio_num_t PIN_OLED_I2C_SDA = GPIO_NUM_7;
static constexpr gpio_num_t PIN_OLED_I2C_SCL = GPIO_NUM_6;
static constexpr gpio_num_t PIN_CTRL_I2C_SDA = GPIO_NUM_2;
static constexpr gpio_num_t PIN_CTRL_I2C_SCL = GPIO_NUM_3;
static constexpr uint8_t SSD1306_ADDR_A = 0x3C;
static constexpr uint8_t SSD1306_ADDR_B = 0x3D;

static constexpr uint32_t HEARTBEAT_MS = 1000;
static constexpr uint32_t ATTRACT_SLOT_MS = 120;
static constexpr uint32_t ATTRACT_ON_MS = 10;
static constexpr uint32_t SWITCH_SCAN_ROW_MS = 5;
static constexpr uint32_t SWITCH_SCAN_ROW_US = SWITCH_SCAN_ROW_MS * 1000U;
static constexpr uint32_t ROW_BLANK_US = 100;
static constexpr uint32_t ROW_SETTLE_US = 100;
static constexpr uint32_t ROW_OFF_DEADTIME_US = 50;
static constexpr uint32_t DISPLAY_FRAME_MS = 50;
static constexpr uint32_t DISPLAY_HOLD_MS = 1000;
static constexpr uint32_t DISPLAY_SCROLL_REV_MS = 5000;
static constexpr uint32_t LINK_STALL_MS = 500;
static constexpr uint32_t TRACE_MODE_PERIOD_MS = 4000;
static constexpr uint8_t MAX_TRACE_ACTIVITY = 46;
static constexpr uint8_t SR_ROW_COUNT = 8;
static constexpr uint8_t SR_COL_COUNT = 4;
static constexpr bool SR_OUTPUT_ACTIVE_LOW = false;
static constexpr bool SW_ACTIVE_LOW = true;
static constexpr int DISPLAY_W = 128;
static constexpr int DISPLAY_H = 64;
static uint8_t s_framebuffer[(DISPLAY_W * DISPLAY_H) / 8] = {};

enum class RuntimeMode : uint8_t
{
  LampAttract = 0,
  SwitchScan = 1,
  I2cSlaveRegmap = 2,
};

enum class RowPhase : uint8_t
{
  Blank = 0,
  Drive = 1,
  Settle = 2,
  Sample = 3,
  Hold = 4,
};

struct RowScheduler
{
  RowPhase phase;
  uint8_t activeRow;
  uint8_t nextRow;
  uint64_t slotStartUs;
  uint64_t phaseDeadlineUs;
  uint32_t overruns;
};

static constexpr RuntimeMode kRuntimeMode = RuntimeMode::I2cSlaveRegmap;

static constexpr uint8_t CAPTAIN_MATRIX_I2C_ADDRESS = 0x24;
static constexpr uint8_t CAPTAIN_MATRIX_REG_LAMP_BASE = 0x00;
static constexpr uint8_t CAPTAIN_MATRIX_REG_LAMP_END = 0x07;
static constexpr uint8_t CAPTAIN_MATRIX_REG_SWITCH_BASE = 0x40;
static constexpr uint8_t CAPTAIN_MATRIX_REG_SWITCH_END = 0x43;
static constexpr uint8_t CAPTAIN_MATRIX_REG_DIAG_BASE = 0xF0;
static constexpr uint8_t CAPTAIN_MATRIX_REG_DIAG_END = 0xF3;
static constexpr uint8_t CAPTAIN_MATRIX_CMD_SYSTEM_SETUP = 0x20;
static constexpr uint8_t CAPTAIN_MATRIX_CMD_SYSTEM_ENABLE = 0x01;
static constexpr uint8_t CAPTAIN_MATRIX_CMD_OUTPUT_SETUP = 0x80;
static constexpr uint8_t CAPTAIN_MATRIX_CMD_OUTPUT_ENABLE = 0x01;
static constexpr uint8_t CAPTAIN_MATRIX_CMD_PULSE_WIDTH_BASE = 0xE0;
static constexpr uint8_t CAPTAIN_MATRIX_CMD_PULSE_WIDTH_MASK = 0x0F;
static constexpr uint8_t CAPTAIN_MATRIX_DEFAULT_PULSE_WIDTH_LEVEL = 4;
static constexpr uint8_t CAPTAIN_MATRIX_DIAG_FLAG_SYSTEM_ENABLED = 0x01;
static constexpr uint8_t CAPTAIN_MATRIX_DIAG_FLAG_OUTPUT_ENABLED = 0x02;
static constexpr size_t CAPTAIN_SWITCH_BYTES = 4;
static constexpr size_t CAPTAIN_LAMP_BYTES = 8;
static constexpr uint8_t CAPTAIN_LAMP_COLS = 5;
static constexpr i2c_port_t CAPTAIN_SLAVE_PORT = I2C_NUM_0;
static constexpr int CAPTAIN_SLAVE_RX_BUF = 128;
static constexpr int CAPTAIN_SLAVE_TX_BUF = 128;
static constexpr int OLED_SW_I2C_DELAY_US = 4;

struct MatrixSlaveRuntime
{
  uint8_t lampRows[CAPTAIN_LAMP_BYTES];
  uint8_t switchBytes[CAPTAIN_SWITCH_BYTES];
  uint8_t readPointer;
  uint8_t pulseWidthLevel;
  bool systemEnabled;
  bool outputEnabled;
  bool linkSeen;
  uint32_t rxPackets;
  uint32_t txWindows;
  uint32_t badWrites;
  uint32_t ignoredWrites;
};

static MatrixSlaveRuntime s_matrixSlave = {
    {},
    {},
    CAPTAIN_MATRIX_REG_SWITCH_BASE,
    CAPTAIN_MATRIX_DEFAULT_PULSE_WIDTH_LEVEL,
    false,
    false,
    false,
    0,
    0,
    0,
    0};

static bool is_lamp_register(uint8_t reg)
{
  return (reg >= CAPTAIN_MATRIX_REG_LAMP_BASE) && (reg <= CAPTAIN_MATRIX_REG_LAMP_END);
}

static bool is_switch_register(uint8_t reg)
{
  return (reg >= CAPTAIN_MATRIX_REG_SWITCH_BASE) && (reg <= CAPTAIN_MATRIX_REG_SWITCH_END);
}

static bool is_diag_register(uint8_t reg)
{
  return (reg >= CAPTAIN_MATRIX_REG_DIAG_BASE) && (reg <= CAPTAIN_MATRIX_REG_DIAG_END);
}

enum class LinkState : uint8_t
{
  Wait = 0,
  Live = 1,
  Degraded = 2,
};

static LinkState current_link_state(bool linkDegraded)
{
  if (s_matrixSlave.rxPackets == 0)
  {
    return LinkState::Wait;
  }
  if (linkDegraded)
  {
    return LinkState::Degraded;
  }
  return LinkState::Live;
}

static const char* link_state_name(LinkState state)
{
  switch (state)
  {
    case LinkState::Wait:
      return "WAIT";
    case LinkState::Degraded:
      return "DEGRADED";
    case LinkState::Live:
    default:
      return "LIVE";
  }
}

static uint8_t matrix_diag_value(uint8_t reg)
{
  switch (reg)
  {
    case 0xF0:
    {
      uint8_t flags = 0;
      if (s_matrixSlave.systemEnabled)
      {
        flags |= CAPTAIN_MATRIX_DIAG_FLAG_SYSTEM_ENABLED;
      }
      if (s_matrixSlave.outputEnabled)
      {
        flags |= CAPTAIN_MATRIX_DIAG_FLAG_OUTPUT_ENABLED;
      }
      return flags;
    }
    case 0xF1:
      return static_cast<uint8_t>(s_matrixSlave.pulseWidthLevel & CAPTAIN_MATRIX_CMD_PULSE_WIDTH_MASK);
    case 0xF2:
      return static_cast<uint8_t>(s_matrixSlave.rxPackets & 0xFFU);
    case 0xF3:
      return static_cast<uint8_t>(s_matrixSlave.txWindows & 0xFFU);
    default:
      return 0;
  }
}

static void matrix_prepare_tx_window(uint8_t startReg)
{
  uint8_t txBuf[CAPTAIN_LAMP_BYTES] = {};
  size_t txLen = 1;
  if (is_switch_register(startReg))
  {
    const uint8_t offset = static_cast<uint8_t>(startReg - CAPTAIN_MATRIX_REG_SWITCH_BASE);
    txLen = CAPTAIN_SWITCH_BYTES - offset;
    for (size_t i = 0; i < txLen; ++i)
    {
      txBuf[i] = s_matrixSlave.switchBytes[offset + i];
    }
    s_matrixSlave.readPointer = CAPTAIN_MATRIX_REG_SWITCH_END;
  }
  else if (is_lamp_register(startReg))
  {
    const uint8_t offset = static_cast<uint8_t>(startReg - CAPTAIN_MATRIX_REG_LAMP_BASE);
    txLen = CAPTAIN_LAMP_BYTES - offset;
    for (size_t i = 0; i < txLen; ++i)
    {
      txBuf[i] = s_matrixSlave.lampRows[offset + i];
    }
    s_matrixSlave.readPointer = CAPTAIN_MATRIX_REG_LAMP_END;
  }
  else if (is_diag_register(startReg))
  {
    uint8_t diag[4] = {
        matrix_diag_value(0xF0),
        matrix_diag_value(0xF1),
        matrix_diag_value(0xF2),
        matrix_diag_value(0xF3)};
    const uint8_t offset = static_cast<uint8_t>(startReg - CAPTAIN_MATRIX_REG_DIAG_BASE);
    txLen = sizeof(diag) - offset;
    for (size_t i = 0; i < txLen; ++i)
    {
      txBuf[i] = diag[offset + i];
    }
    s_matrixSlave.readPointer = CAPTAIN_MATRIX_REG_DIAG_END;
  }
  else
  {
    txBuf[0] = 0;
    txLen = 1;
  }

  i2c_reset_tx_fifo(CAPTAIN_SLAVE_PORT);
  const int queued = i2c_slave_write_buffer(CAPTAIN_SLAVE_PORT, txBuf, txLen, 0);
  if (queued > 0)
  {
    s_matrixSlave.txWindows++;
  }
}

static void matrix_handle_command(uint8_t command)
{
  if ((command & 0xF0U) == CAPTAIN_MATRIX_CMD_PULSE_WIDTH_BASE)
  {
    s_matrixSlave.pulseWidthLevel = static_cast<uint8_t>(command & CAPTAIN_MATRIX_CMD_PULSE_WIDTH_MASK);
    return;
  }

  if ((command & 0xFEU) == CAPTAIN_MATRIX_CMD_SYSTEM_SETUP)
  {
    s_matrixSlave.systemEnabled = ((command & CAPTAIN_MATRIX_CMD_SYSTEM_ENABLE) != 0U);
    return;
  }

  if ((command & 0xFEU) == CAPTAIN_MATRIX_CMD_OUTPUT_SETUP)
  {
    s_matrixSlave.outputEnabled = ((command & CAPTAIN_MATRIX_CMD_OUTPUT_ENABLE) != 0U);
  }
}

static void matrix_handle_write_packet(const uint8_t* packet, size_t length)
{
  if ((packet == nullptr) || (length == 0))
  {
    return;
  }

  s_matrixSlave.linkSeen = true;
  s_matrixSlave.rxPackets++;

  const uint8_t first = packet[0];
  if ((length == 1) && (((first & 0xFEU) == CAPTAIN_MATRIX_CMD_SYSTEM_SETUP) ||
                        ((first & 0xFEU) == CAPTAIN_MATRIX_CMD_OUTPUT_SETUP) ||
                        (first & 0xF0U) == CAPTAIN_MATRIX_CMD_PULSE_WIDTH_BASE))
  {
    matrix_handle_command(first);
    matrix_prepare_tx_window(s_matrixSlave.readPointer);
    return;
  }

  s_matrixSlave.readPointer = first;
  if (length == 1)
  {
    matrix_prepare_tx_window(s_matrixSlave.readPointer);
    return;
  }

  if (!is_lamp_register(first))
  {
    s_matrixSlave.ignoredWrites += static_cast<uint32_t>(length - 1U);
    matrix_prepare_tx_window(s_matrixSlave.readPointer);
    return;
  }

  for (size_t idx = 1; idx < length; ++idx)
  {
    const uint8_t reg = static_cast<uint8_t>(first + (idx - 1));
    const uint8_t value = packet[idx];
    if (is_lamp_register(reg))
    {
      s_matrixSlave.lampRows[reg - CAPTAIN_MATRIX_REG_LAMP_BASE] = static_cast<uint8_t>(value & 0x1FU);
    }
    else if (is_switch_register(reg) || is_diag_register(reg))
    {
      s_matrixSlave.ignoredWrites++;
    }
    else
    {
      s_matrixSlave.ignoredWrites++;
    }
  }

  matrix_prepare_tx_window(s_matrixSlave.readPointer);
}

static void matrix_pack_switch_bytes(const bool swState[SR_ROW_COUNT][SR_COL_COUNT])
{
  for (uint8_t col = 0; col < SR_COL_COUNT; ++col)
  {
    uint8_t byteValue = 0;
    for (uint8_t row = 0; row < SR_ROW_COUNT; ++row)
    {
      if (swState[row][col])
      {
        byteValue = static_cast<uint8_t>(byteValue | static_cast<uint8_t>(1U << row));
      }
    }
    s_matrixSlave.switchBytes[col] = byteValue;
  }
}

static void matrix_print_buffer_view(void)
{
  static bool hasPrev = false;
  static uint8_t prevRows[CAPTAIN_LAMP_BYTES] = {};

  std::printf("VIEW sys=%u out=%u pulse=%u reg=0x%02X rx=%lu tx=%lu badW=%lu ignW=%lu\n",
              static_cast<unsigned>(s_matrixSlave.systemEnabled ? 1 : 0),
              static_cast<unsigned>(s_matrixSlave.outputEnabled ? 1 : 0),
              static_cast<unsigned>(s_matrixSlave.pulseWidthLevel),
              static_cast<unsigned>(s_matrixSlave.readPointer),
              static_cast<unsigned long>(s_matrixSlave.rxPackets),
              static_cast<unsigned long>(s_matrixSlave.txWindows),
              static_cast<unsigned long>(s_matrixSlave.badWrites),
              static_cast<unsigned long>(s_matrixSlave.ignoredWrites));
  std::printf("      C0 C1 C2 C3 C4   HEX  D\n");
  for (uint8_t row = 0; row < CAPTAIN_LAMP_BYTES; ++row)
  {
    const uint8_t rowMask = s_matrixSlave.lampRows[row];
    const bool changed = hasPrev && (rowMask != prevRows[row]);
    std::printf("R%u |  %c  %c  %c  %c  %c   0x%02X  %c\n",
                static_cast<unsigned>(row),
                (rowMask & (1U << 0)) ? 'X' : '.',
                (rowMask & (1U << 1)) ? 'X' : '.',
                (rowMask & (1U << 2)) ? 'X' : '.',
                (rowMask & (1U << 3)) ? 'X' : '.',
                (rowMask & (1U << 4)) ? 'X' : '.',
                static_cast<unsigned>(rowMask),
                changed ? '!' : '.');
    prevRows[row] = rowMask;
  }
  hasPrev = true;
}

struct LinkStats
{
  uint32_t sdaEdges;
  uint32_t sclEdges;
  bool active;
};

struct LampPoint
{
  uint8_t row;
  uint8_t col;
};

static constexpr LampPoint kAttractOrder[] = {
    {4, 0}, {1, 0}, {3, 0},
    {4, 2},
    {2, 0}, {0, 0}, {5, 2},
    {2, 2},
    {1, 2},
    {3, 2},
    {0, 2},
    {1, 1}, {0, 1}, {4, 1},
    {2, 1}, {3, 1}, {5, 1},
    {4, 3},
    {1, 3}, {2, 3}, {3, 3}, {0, 3},
    {6, 0}, {7, 3}};

  static void fb_clear(void);
static void fb_set_pixel(int x, int y, bool on);

static inline void oled_sw_i2c_delay(void)
{
  esp_rom_delay_us(OLED_SW_I2C_DELAY_US);
}

static inline void oled_sw_sda(int level)
{
  gpio_set_level(PIN_OLED_I2C_SDA, level);
}

static inline void oled_sw_scl(int level)
{
  gpio_set_level(PIN_OLED_I2C_SCL, level);
}

static void oled_sw_i2c_start(void)
{
  oled_sw_sda(1);
  oled_sw_scl(1);
  oled_sw_i2c_delay();
  oled_sw_sda(0);
  oled_sw_i2c_delay();
  oled_sw_scl(0);
}

static void oled_sw_i2c_stop(void)
{
  oled_sw_sda(0);
  oled_sw_i2c_delay();
  oled_sw_scl(1);
  oled_sw_i2c_delay();
  oled_sw_sda(1);
  oled_sw_i2c_delay();
}

static bool oled_sw_i2c_write_byte(uint8_t value)
{
  for (int bit = 7; bit >= 0; --bit)
  {
    oled_sw_sda((value >> bit) & 0x01U);
    oled_sw_i2c_delay();
    oled_sw_scl(1);
    oled_sw_i2c_delay();
    oled_sw_scl(0);
  }

  oled_sw_sda(1);
  oled_sw_i2c_delay();
  oled_sw_scl(1);
  oled_sw_i2c_delay();
  const bool ack = (gpio_get_level(PIN_OLED_I2C_SDA) == 0);
  oled_sw_scl(0);
  return ack;
}

static esp_err_t ssd1306_sw_write(uint8_t control, const uint8_t* data, size_t len)
{
  oled_sw_i2c_start();
  if (!oled_sw_i2c_write_byte(static_cast<uint8_t>(SSD1306_ADDR_A << 1)))
  {
    oled_sw_i2c_stop();
    return ESP_FAIL;
  }
  if (!oled_sw_i2c_write_byte(control))
  {
    oled_sw_i2c_stop();
    return ESP_FAIL;
  }
  for (size_t i = 0; i < len; ++i)
  {
    if (!oled_sw_i2c_write_byte(data[i]))
    {
      oled_sw_i2c_stop();
      return ESP_FAIL;
    }
  }
  oled_sw_i2c_stop();
  return ESP_OK;
}
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
extern "C" void app_main(void)
{
  std::printf("\n=== Matrix Rev1 SAFE HEARTBEAT FW ===\n");
  std::printf("Build: %s %s\n", __DATE__, __TIME__);
  std::printf("Mode: logic-only, no lamp drive\n");
  std::printf("SW_COL map: 0=GPIO18 1=GPIO19 2=GPIO20 3=GPIO21\n");
  std::printf("SR map: DATA=GPIO15 CLK=GPIO22 LATCH=GPIO23 OE_N=GPIO10\n");
  std::printf("SR chain: U4=row byte (2nd shifted), U5=col byte (1st shifted)\n");
  if (kRuntimeMode == RuntimeMode::LampAttract)
  {
    std::printf("Runtime mode: LAMP_ATTRACT slot=%lums on=%lums steps=%u\n",
                static_cast<unsigned long>(ATTRACT_SLOT_MS),
                static_cast<unsigned long>(ATTRACT_ON_MS),
                static_cast<unsigned>(sizeof(kAttractOrder) / sizeof(kAttractOrder[0])));
  }
  else if (kRuntimeMode == RuntimeMode::I2cSlaveRegmap)
  {
    std::printf("Runtime mode: I2C_SLAVE_REGMAP addr=0x%02X SDA=GPIO2 SCL=GPIO3\n",
                CAPTAIN_MATRIX_I2C_ADDRESS);
  }
  else
  {
    std::printf("Runtime mode: SWITCH_SCAN row_step=%lums sw_active=%s\n",
                static_cast<unsigned long>(SWITCH_SCAN_ROW_MS),
                SW_ACTIVE_LOW ? "LOW" : "HIGH");
  }
  std::printf("OLED I2C map: SDA=GPIO7 SCL=GPIO6 (try SSD1306 0x3C / 0x3D)\n");
  std::printf("CTRL link pins: SDA=GPIO2 SCL=GPIO3\n");

  const uint64_t inputMask =
      (1ULL << PIN_SW_COL0) |
      (1ULL << PIN_SW_COL1) |
      (1ULL << PIN_SW_COL2) |
      (1ULL << PIN_SW_COL3);

  gpio_config_t inputCfg = {};
  inputCfg.pin_bit_mask = inputMask;
  inputCfg.mode = GPIO_MODE_INPUT;
  inputCfg.pull_up_en = GPIO_PULLUP_DISABLE;
  inputCfg.pull_down_en = GPIO_PULLDOWN_DISABLE;
  inputCfg.intr_type = GPIO_INTR_DISABLE;

  const esp_err_t cfgErr = gpio_config(&inputCfg);
  std::printf("gpio_config(SW_COL) -> %d\n", static_cast<int>(cfgErr));

  const uint64_t outputMask =
      (1ULL << PIN_SR_DATA) |
      (1ULL << PIN_SR_CLK) |
      (1ULL << PIN_SR_LATCH) |
      (1ULL << PIN_SR_OE_N);
  gpio_config_t outputCfg = {};
  outputCfg.pin_bit_mask = outputMask;
  outputCfg.mode = GPIO_MODE_OUTPUT;
  outputCfg.pull_up_en = GPIO_PULLUP_DISABLE;
  outputCfg.pull_down_en = GPIO_PULLDOWN_DISABLE;
  outputCfg.intr_type = GPIO_INTR_DISABLE;

  const esp_err_t outErr = gpio_config(&outputCfg);
  std::printf("gpio_config(SR out) -> %d\n", static_cast<int>(outErr));
  gpio_set_level(PIN_SR_DATA, 0);
  gpio_set_level(PIN_SR_CLK, 0);
  gpio_set_level(PIN_SR_LATCH, 0);
  gpio_set_level(PIN_SR_OE_N, 0);
  std::printf("SR OE_N level -> %d (0 means outputs enabled)\n", gpio_get_level(PIN_SR_OE_N));

  esp_err_t ctrlCfgErr = ESP_OK;
  if (kRuntimeMode != RuntimeMode::I2cSlaveRegmap)
  {
    gpio_config_t ctrlI2cCfg = {};
    ctrlI2cCfg.pin_bit_mask = (1ULL << PIN_CTRL_I2C_SDA) | (1ULL << PIN_CTRL_I2C_SCL);
    ctrlI2cCfg.mode = GPIO_MODE_INPUT;
    ctrlI2cCfg.pull_up_en = GPIO_PULLUP_DISABLE;
    ctrlI2cCfg.pull_down_en = GPIO_PULLDOWN_DISABLE;
    ctrlI2cCfg.intr_type = GPIO_INTR_DISABLE;
    ctrlCfgErr = gpio_config(&ctrlI2cCfg);
    std::printf("gpio_config(CTRL I2C monitor) -> %d\n", static_cast<int>(ctrlCfgErr));
  }
  int prevCtrlSda = gpio_get_level(PIN_CTRL_I2C_SDA);
  int prevCtrlScl = gpio_get_level(PIN_CTRL_I2C_SCL);

  esp_err_t busErr = ESP_FAIL;
  i2c_master_bus_handle_t busHandle = nullptr;
  if (kRuntimeMode != RuntimeMode::I2cSlaveRegmap)
  {
    log_i2c_line_levels();

    i2c_master_bus_config_t busCfg = {};
    busCfg.i2c_port = I2C_NUM_0;
    busCfg.sda_io_num = PIN_OLED_I2C_SDA;
    busCfg.scl_io_num = PIN_OLED_I2C_SCL;
    busCfg.clk_source = I2C_CLK_SRC_DEFAULT;
    busCfg.glitch_ignore_cnt = 7;
    busCfg.flags.enable_internal_pullup = true;

    busErr = i2c_new_master_bus(&busCfg, &busHandle);
    std::printf("i2c_new_master_bus -> %d (%s)\n",
                static_cast<int>(busErr),
                esp_err_to_name(busErr));
  }

  if (kRuntimeMode == RuntimeMode::I2cSlaveRegmap)
  {
    i2c_config_t slaveCfg = {};
    slaveCfg.mode = I2C_MODE_SLAVE;
    slaveCfg.sda_io_num = PIN_CTRL_I2C_SDA;
    slaveCfg.sda_pullup_en = GPIO_PULLUP_ENABLE;
    slaveCfg.scl_io_num = PIN_CTRL_I2C_SCL;
    slaveCfg.scl_pullup_en = GPIO_PULLUP_ENABLE;
    slaveCfg.slave.addr_10bit_en = 0;
    slaveCfg.slave.slave_addr = CAPTAIN_MATRIX_I2C_ADDRESS;

    const esp_err_t paramErr = i2c_param_config(CAPTAIN_SLAVE_PORT, &slaveCfg);
    std::printf("i2c_param_config(slave) -> %d (%s)\n",
                static_cast<int>(paramErr),
                esp_err_to_name(paramErr));
    const esp_err_t installErr = (paramErr == ESP_OK)
                                     ? i2c_driver_install(CAPTAIN_SLAVE_PORT,
                                                          I2C_MODE_SLAVE,
                                                          CAPTAIN_SLAVE_RX_BUF,
                                                          CAPTAIN_SLAVE_TX_BUF,
                                                          0)
                                     : paramErr;
    std::printf("i2c_driver_install(slave) -> %d (%s)\n",
                static_cast<int>(installErr),
                esp_err_to_name(installErr));
    if (installErr == ESP_OK)
    {
      matrix_prepare_tx_window(s_matrixSlave.readPointer);
    }
  }

  i2c_master_dev_handle_t oledHandle = nullptr;
  uint8_t oledAddrInUse = 0;
  esp_err_t oledInitErr = ESP_FAIL;
  bool oledSwReady = false;
  static constexpr char kScrollMsg[] = "Matrix boad rev 1";
  const int msgPixelWidth = (static_cast<int>(sizeof(kScrollMsg)) - 1) * 6;
  int lastStartX = 0;
  esp_err_t lastFlushErr = ESP_OK;
  if ((kRuntimeMode != RuntimeMode::I2cSlaveRegmap) && (busErr == ESP_OK))
  {
    uint8_t firstI2cAddr = 0;
    const bool foundAny = scan_i2c_bus(busHandle, &firstI2cAddr);

    oledInitErr = try_oled_address(busHandle, SSD1306_ADDR_A, &oledHandle);
    if (oledInitErr == ESP_OK)
    {
      oledAddrInUse = SSD1306_ADDR_A;
    }
    else
    {
      oledInitErr = try_oled_address(busHandle, SSD1306_ADDR_B, &oledHandle);
      if (oledInitErr == ESP_OK)
      {
        oledAddrInUse = SSD1306_ADDR_B;
      }
    }

    if ((oledInitErr != ESP_OK) && foundAny)
    {
      std::printf("Trying first detected I2C address 0x%02X as OLED candidate\n", firstI2cAddr);
      oledInitErr = try_oled_address(busHandle, firstI2cAddr, &oledHandle);
      if (oledInitErr == ESP_OK)
      {
        oledAddrInUse = firstI2cAddr;
      }
    }
  }
  else if (kRuntimeMode == RuntimeMode::I2cSlaveRegmap)
  {
    oledInitErr = ssd1306_sw_init();
    oledSwReady = (oledInitErr == ESP_OK);
    std::printf("ssd1306_sw_init(GPIO7/6 @0x3C) -> %d (%s)\n",
                static_cast<int>(oledInitErr),
                esp_err_to_name(oledInitErr));
  }

  uint32_t beat = 0;
  uint8_t activeRow = kAttractOrder[0].row;
  uint8_t activeCol = kAttractOrder[0].col;
  uint8_t activeColByte = static_cast<uint8_t>(1U << activeCol);
  uint8_t attractStep = 0;
  uint16_t activeFrame = sr_compose_frame(static_cast<uint8_t>(1U << activeRow),
                                          activeColByte);
  uint32_t ctrlSdaEdges = 0;
  uint32_t ctrlSclEdges = 0;
  uint32_t sw0Edges = 0;
  uint32_t sw1Edges = 0;
  uint32_t sw2Edges = 0;
  uint32_t sw3Edges = 0;
  uint32_t swHits[SR_ROW_COUNT][SR_COL_COUNT] = {};
  bool swState[SR_ROW_COUNT][SR_COL_COUNT] = {};
  LinkStats lastLinkStats = {0, 0, false};
  int prevSw0 = gpio_get_level(PIN_SW_COL0);
  int prevSw1 = gpio_get_level(PIN_SW_COL1);
  int prevSw2 = gpio_get_level(PIN_SW_COL2);
  int prevSw3 = gpio_get_level(PIN_SW_COL3);

  const uint64_t bootUs = static_cast<uint64_t>(esp_timer_get_time());
  const uint64_t bootMs = bootUs / 1000U;
  uint64_t lastHeartbeatMs = 0;
  uint64_t lastDisplayMs = 0;
  uint64_t txStallStartMs = 0;
  uint32_t prevRxPackets = s_matrixSlave.rxPackets;
  uint32_t prevTxWindows = s_matrixSlave.txWindows;
  uint32_t lastDisplayRx = s_matrixSlave.rxPackets;
  uint32_t lastDisplayTx = s_matrixSlave.txWindows;
  bool linkDegraded = false;
  RowScheduler rowScheduler = {
      RowPhase::Blank,
      0,
      0,
      bootUs,
      bootUs + ROW_BLANK_US,
      0};

  if (kRuntimeMode != RuntimeMode::LampAttract)
  {
    activeRow = rowScheduler.activeRow;
    activeCol = 0;
    activeColByte = 0;
    activeFrame = sr_write_image(0x00, 0x00);
  }

  while (true)
  {
    const uint64_t nowUs = static_cast<uint64_t>(esp_timer_get_time());
    const uint64_t nowMs = nowUs / 1000U;
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

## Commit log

2026-04-06 Reorganize repo structure and add starter project scaffold
    [Pinball Matrix board Rev 1.kicad_pcb, Pinball Matrix board Rev 1.kicad_sch]
2026-04-06 Switch ESP32-C6 bring-up scaffold to ESP-IDF
2026-04-06 Track ESP-IDF project files and ignore generated config
2026-04-06 Add pinmap and board-mating draft notes
2026-04-06 Add schematic review and cleanup notes
2026-04-07 Add follow-up block-by-block schematic review
2026-04-07 Add files via upload
    Made seveal additions it's close to being complete before final review
    [Pinball Matrix board Rev 1.kicad_pcb, Pinball Matrix board Rev 1.kicad_sch]
2026-04-08 Add files via upload
    cleaned up some foot print errors and changed tvs diodes on all 3 rail because of their size physically there were 0201's
    [Pinball Matrix board Rev 1.kicad_pcb, Pinball Matrix board Rev 1.kicad_sch]
2026-04-08 Add files via upload
    misc error clean up changes
    [Pinball Matrix board Rev 1.kicad_pcb, Pinball Matrix board Rev 1.kicad_sch]
2026-04-08 Add files via upload
    The update PBC errors are clean
    [Pinball Matrix board Rev 1.kicad_pcb, Pinball Matrix board Rev 1.kicad_sch]
2026-04-08 Update schematic review with latest comparator findings
2026-04-08 WIP matrix board placement and routing prep
    [Pinball Matrix board Rev 1.kicad_pcb, Pinball Matrix board Rev 1.kicad_sch]
2026-04-09 before PCB purchase
    [Pinball Matrix board Rev 1.kicad_pcb, Pinball Matrix board Rev 1.kicad_sch]
2026-04-09 added production files
    [Pinball Matrix board BOM_ Rev 1.csv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]
2026-04-09 Document current pre-order repo status
2026-04-27 bringup: 5V/3V3 confirmed; structured bring-up firmware + doc updates
    - firmware/src/main.cpp: refactored into three explicit bring-up phases:
    Phase 1 - walking-1 across all 16 SR bits (scope/LA confirmation)
    Phase 2 - switch-column poll with change-only output (10 s window)
    Phase 3 - one-row/one-column lamp test (2x2 to start, expand safely)
    then continuous SW_COL monitor loop
    - docs/PROJECT_STATUS.md: reflect 5V+3.3V rails up; phase = active bring-up
    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
2026-04-28 Add switch-scan bring-up mode and update checkpoint docs
2026-04-28 Checkpoint: Rev1 hardware edits and firmware platform config
    [Pinball Matrix board Rev 1.kicad_pcb, Pinball Matrix board Rev 1.kicad_pcb pre route.kicad_pcb, Pinball Matrix board Rev 1.kicad_sch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]
2026-04-28 hardware: save latest matrix PCB rev; gitignore lock files and backups
2026-04-28 fix: remove platform_packages pin that broke CI on GitHub runners
2026-05-03 Stabilize matrix SR timing and handoff
    [main.cpp]
2026-05-03 ci: pin espressif32 to 6.13.0 to fix CI broken by 7.0.0 release
